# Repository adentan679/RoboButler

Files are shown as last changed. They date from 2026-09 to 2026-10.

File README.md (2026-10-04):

# RoboButler — Person-Following Rover with Gesture-Controlled Item Access

A robotics prototype developed for **UC San Diego ECE/MAE 148**, designed to follow an AprilTag target and provide access to stored items through a rotating compartment and motorized scissor lift.

**My role:** Hardware integration, Raspberry Pi–Arduino communication, motor control, power distribution, and debugging.

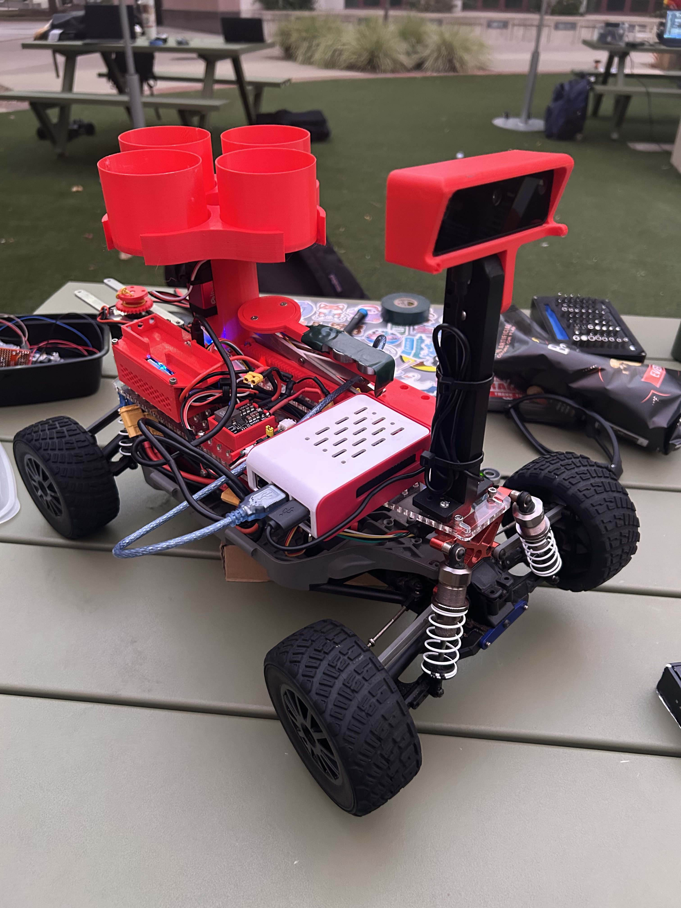
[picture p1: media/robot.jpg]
RoboButler assembled prototype


## Overview

Walking between classes across UCSD's large campus can be tiring, especially while carrying a heavy backpack. Our team explored a robot that could follow a student carrying an AprilTag and transport some of their belongings.

At the destination, hand gestures select a compartment position and extend a stepper-driven scissor lift to make items easier to reach. A fist commands the lift to retract. The intended lift travel was approximately a couple of feet; measured travel and payload capacity have not been established.

**Project status:** Navigation and gesture-controlled actuation were tested on hardware as course subsystems. This repository presents them as a **single coordinated application** with navigation-to-gesture handoff, actuator command tracking, camera ownership control, and return-to-navigation logic. The integrated software path has been validated with **62 automated tests** and a complete simulated operating sequence. The available project evidence does not establish an end-to-end physical test of this exact integrated build.

## Course Demonstrations

These videos document the two major hardware subsystems developed for the course. They demonstrate gesture-controlled actuation and AprilTag-based navigation work, rather than a complete end-to-end run of the current integrated application.

- [Hand Gesture Control Demonstration](https://youtu.be/hY5M1MJWAxY)
- [AprilTag Detection Demonstration](https://youtube.com/shorts/GXT1gASVuJs)

## My Contributions

My work focused on connecting and debugging the robot's electronics and actuators:

- Integrated Raspberry Pi-to-Arduino Mega USB serial communication for gesture-driven motor commands.
- Developed Arduino control for compartment servo positioning and stepper-driven lift extension and retraction.
- Wired and configured the DRV8825 stepper driver and investigated motor response and connection issues.
- Integrated power distribution for the vehicle electronics, servo, and stepper motor.
- Troubleshot wiring, serial communication, actuator operation, and driver overheating.
- Adjusted the driver's current-limit setting during hardware debugging.

One stepper driver overheated and was replaced. I recall reducing the replacement driver's reference voltage from approximately **1.0 V to 0.5 V** while troubleshooting heat. These are recalled Vref settings, not verified motor-current measurements; the current relationship depends on the actual driver module.

Navigation software and mechanical design were team efforts. The active repository combines the navigation, gesture, Arduino, and vehicle-control components under one supervisor while preserving the original course subsystem code in `archive/software/` for traceability.

## How the Integrated System Works

The Raspberry Pi runs a coordinator that manages navigation, camera ownership, gesture recognition, and Arduino commands. Because the navigation and gesture code use different DepthAI APIs, they run in **separate Python environments**, with only one vision process owning the OAK-D Lite at a time.

```mermaid
flowchart TD
    NAV["Navigate toward selected AprilTag"] --> STOP["Request vehicle stop"]
    STOP -->|"Operator confirms standstill"| GEST["Release navigation camera; start gesture mode"]
    GEST -->|"Selection gesture"| EXT["Rotate compartment and extend lift"]
    EXT -->|"Fist"| RET["Retract lift; remain parked"]
    RET -->|"Motion complete and operator confirms stow"| READY["Ready to resume"]
    READY -->|"Hold thumbs-up for two seconds"| SWITCH["Release gesture camera; restart navigation"]
    SWITCH --> NAV
```

The coordinator keeps the Arduino connection open across mode changes and requires a camera worker to release its resources and exit before starting the next worker. Gesture processing runs independently of the optional video preview.

**A completed movement command does not prove physical position.** Hardware mode still requires operator confirmation that the vehicle has stopped and that the lift is stowed. Thumbs-up replaces the typed resume command after stow confirmation. Navigation then requires a fresh observation of the selected tag; if the tag remains within the arrival threshold, the vehicle stays parked.

### Gesture Commands

| Gesture | Requested action |
|---|---|
| Point | Servo to 0°, then extend the lift |
| Peace | Servo to 90°, then extend the lift |
| Thumb, index, middle, and ring extended; pinky folded | Servo to 180°, then extend the lift |
| Open palm | Servo to 270°, then extend the lift |
| Fist | Retract the lift and remain parked |
| Upright thumbs-up held for two seconds | Resume navigation after confirmed stow |

These angles are inherited software settings. The physical servo's supported travel and pulse range still need verification. Additional compartment selections are blocked while the lift is extended or an actuator command is pending.

## Hardware and Software

| Area | Components and tools |
|---|---|
| Computing and vision | Raspberry Pi, OAK-D Lite, Arduino Mega |
| Vehicle control | RC chassis, VESC motor controller, drive motor, steering servo |
| Item access | Compartment servo, stepper motor, DRV8825 driver, scissor lift |
| Power | Approximately 15 V LiPo, anti-spark switch, actuator conversion to 5 V for the servo and 12 V for the motor supply |
| Navigation | AprilTag detection, RGB/depth processing, FastSAM, Pure Pursuit control |
| Gesture recognition | MediaPipe Hands, rule-based classification, gesture stability filtering |
| Integration | Python processes, USB serial, command acknowledgements, nonblocking Arduino firmware |

The navigation controller is named `mpc_controller.py`, but implements **Pure Pursuit steering and proportional command generation**, not optimization-based MPC. EKF code is present, but estimated velocity is overridden in the controller; this is not validated EKF-based speed feedback.

Hardware resources: [power distribution](hardware/schematics/power_distribution.png), [actuator wiring drawing](hardware/schematics/DRV8825_wiring_diagram.png), and [CAD files](hardware/cad/). The drawings document the project and require verification against the actual components before rebuilding. The CAD collection includes inherited chassis designs; a mount's presence does not establish that its corresponding sensor was used on RoboButler.

## Validation and Limitations

| Scope | Evidence and status |
|---|---|
| Course hardware work | Separate navigation and gesture/actuator subsystem testing |
| Integration software | Recorded run of **62 automated tests passing**, with no skips |
| Simulated sequence | Navigation → gesture mode → extension → retraction → confirmed stow → thumbs-up → navigation |
| End-to-end physical run of this exact integrated build | Not established by the available project evidence |

The automated checks exercise mode transitions, camera-process handoff, stale observations, serial failures, command acknowledgements, resume conditions, and firmware behavior with mocked hardware. The demo uses synthetic observations and simulated devices; it does not simulate vehicle dynamics, camera recognition accuracy, or lift mechanics. The firmware check compiles against host-side Arduino mocks, not the Mega toolchain.

Remaining work requires robot access: verify stopping and holding behavior, servo limits, stepper direction and travel, lift position sensing, payload capacity, Pi dependency compatibility, perception performance, and the complete operating sequence. Zero VESC duty may allow coasting and does not establish physical standstill.

See the [validation report](docs/validation.md), [recorded test output](docs/test-results.txt), and [demo output](docs/demo-output.txt).

## Try the Software Demo

From the repository root, using Python 3.10 or newer:

```bash
python run_robot.py --demo
```

No robot, camera, Arduino, DepthAI, or MediaPipe installation is needed for this demo. It should finish with:

```text
PASS: navigation -> gesture -> extend -> retract -> confirmed stow -> thumbs-up -> navigation
```

Run the automated checks with:

```bash
python -m unittest discover -s tests -v
```

Most checks use only Python's standard library. Three controller checks require NumPy, and the firmware check requires `g++`; those checks are skipped if their dependencies are unavailable. On Windows, use `py` if `python` is unavailable.

Hardware operation uses separate navigation and gesture environments and verified USB device identities. See the [integration guide](docs/integration-guide.md) for configuration, operator confirmations, and hardware prerequisites.

## Repository Guide

| Location | Contents |
|---|---|
| `run_robot.py` | Entry point for the demo and supervised hardware mode |
| `software/integration/` | Coordinator, process management, serial interfaces, and simulation |
| `software/navigation/` | Adapted team navigation code and FastSAM model |
| `software/gesture_control/` | Gesture classification and optional video preview |
| `software/arduino/` | Updated servo/stepper firmware for the integration protocol |
| `tests/` | Automated software tests and hardware mocks |
| `docs/` | Integration guide, serial protocol, validation, and source attribution |
| `hardware/` | Power and wiring drawings, CAD, and mounting designs |
| `media/` | Prototype photographs and assembly images |
| `archive/software/` | Original course subsystem code |

The original gesture application used Flask. The integrated application uses an optional read-only preview without Flask. Its Arduino firmware also uses an updated command protocol, so the archived sketch is not interchangeable with the integrated firmware.

## Team Project and Credits

Developed for **ECE/MAE 148 — Introduction to Autonomous Vehicles**, University of California, San Diego, Spring 2026.

This personal portfolio repository highlights my hardware integration, Arduino actuation, power distribution, and debugging contributions. Team-developed navigation software and mechanical designs are retained with attribution, and the active repository presents the project as one coordinated software system while preserving the original course snapshot for traceability.

- [Original team repository](https://github.com/UCSD-Silberman-Classes-and-Projects/spring-2026-final-project-team-17)
- [Source attribution and implementation notes](docs/sources.md)

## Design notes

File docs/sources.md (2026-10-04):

# Source attribution and implementation notes

Original team repository:
https://github.com/UCSD-Silberman-Classes-and-Projects/spring-2026-final-project-team-17/tree/5b2ddda989908b18566bfb2381e0f541582ae974

Navigation modules and FastSAM-s.pt originate in that revision's VisCarPath folder. Gesture landmark rules originate in hand_gesture/gesture_servo_stepper.py. Existing pin assignments, servo mapping and pulse-count settings originate in hand_gesture/project_servo_stepper.ino. Preserve the team's attribution and upstream dependency/model licenses if redistributing this project; this package does not assert a new license over those materials.

Current repository integration layer: supervisor, worker protocol/lifecycle, persistent serial adapters, default simulator, tests and protocol firmware. Adapted for the unified application: camera-only navigation mode, freshness checks, near-endpoint following, FastSAM thread shutdown/failure propagation and VESC stop/port behavior. The original FastSAM weights are copied unchanged; no model inference/training was performed here.

Official API references consulted:

- Luxonis DepthAI v2/v3 migration: https://docs.luxonis.com/software-v3/depthai/tutorials/v2-vs-v3
- Luxonis v3 camera context and output queues: https://docs.luxonis.com/software-v3/depthai/examples/camera/camera_output
- Luxonis host-synchronized monotonic timestamps: https://docs.luxonis.com/software-v3/depthai/depthai-components/device

Hardware mode targets the Raspberry Pi's Linux host. getTimestamp() is the DepthAI host-synchronized monotonic time; getTimestampDevice() is not used for supervisor message age. Pi-side camera/API and installed-wheel compatibility still require validation on that platform.

Gesture-resume update: added a scale-relative upright-thumb rule, timed hold with stow/motion gates, and simulated coverage. The existing selection rules and integrated Arduino firmware are retained.

The active `software/` tree is the current unified implementation. `archive/software/` preserves the original course subsystem snapshot so the source lineage and later coordination changes remain traceable.

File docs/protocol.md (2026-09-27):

# Host/Arduino protocol and ownership

The supervisor owns the Arduino port throughout both modes. Camera workers never write USB serial. The VESC has its own sole writer thread; no other process should run a standalone VESC program concurrently.

Arduino baud: 9600. Lines are ASCII and newline-terminated. Firmware input is bounded to 63 characters. Motion uses a nonblocking loop so PING and STOP can be handled during movement.

| Host message | Arduino response / behavior |
|---|---|
| `HELLO` | `READY ROBOBUTLER1`; establishes heartbeat link |
| `PING` | `PONG`; host sends every 0.5 s |
| `1 STOW` | `ACK 1`, `DONE 1 STOWED`; operator confirmation, no motor movement |
| `2 Command_1` | `ACK 2`; rotate then extend; `DONE 2 EXTENDED` after pulse generation |
| `3 RETURN` | `ACK 3`; retract; `DONE 3 RETRACTED_UNVERIFIED` |
| `STOP` | Stop step pulses, invalidate position; `FAULT STOPPED` |

Use increasing positive command IDs; do not reuse or blindly retry a motion after losing its reply. There is only one pending command. STOW is permitted at boot/unknown or after retraction, not while extended or moving. A selection requires STOWED. RETURN requires EXTENDED. ACK means accepted, DONE means software action finished. Neither message is a position measurement.

Firmware emits `BOOT ROBOBUTLER1` at startup. Receiving BOOT after the host handshake faults the session and invalidates position. Lack of host heartbeat for over two seconds also stops firmware motion and invalidates position. The firmware has no home sensor; automatic position recovery is intentionally absent.

Camera workers send JSON lines with an integer session token and event type. Observation messages include a strictly increasing frame sequence and a host monotonic capture timestamp. Old sessions and repeated frames cannot authorize a new action. READY confirms worker initialization; RELEASED is emitted only after camera cleanup. The parent also requires successful process exit before starting the next owner. Release failure/timeout never permits concurrent camera startup.

The same coordinator consumes simulated and real worker messages. Tests use synthetic detections to validate coordination, not to estimate real-world computer-vision accuracy.

Resume uses a `THUMBS_UP` vision label held for two seconds on fresh frames after acknowledged physical stow. It is handled entirely by the coordinator and is never sent to the Arduino. The terminal `resume` action has been removed. Retraction completion alone still cannot authorize resumption.

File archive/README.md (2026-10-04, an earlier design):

# Original Course Code

This folder preserves the original RoboButler navigation and gesture-controlled actuation code from UC San Diego ECE/MAE 148.

The active implementation lives in the repository root and [`software/`](../software/). It combines navigation, gesture recognition, Arduino actuation, camera handoff, safety interlocks, and return-to-navigation behavior under one supervisor.

This archive is retained only for source traceability and comparison with the active integrated implementation. See the [main README](../README.md) for the current project architecture and validation status.

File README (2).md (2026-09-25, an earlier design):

# Robobutler — Person-Following Rover with Gesture-Controlled Item Access

A robotics prototype developed for **UC San Diego ECE/MAE 148** that combines AprilTag-based navigation with a rotating storage compartment and a motorized scissor lift.

**My role:** Hardware integration, Arduino motor control, power distribution, and system debugging.

<!-- Add a clear photo of the assembled robot here:
![Robobutler assembled prototype](media/robobutler.jpg)
-->

## Overview

Walking between classes across UCSD's large campus can be tiring, especially while carrying a heavy backpack. Our team wanted to explore a robot that could follow a student and carry some of their belongings.

Robobutler uses an **AprilTag as the visual target** for following a person. To make stored items easier to reach, the design combines a **servo-driven rotating compartment** with a **stepper-driven scissor lift**. Hand gestures select a compartment position and command the lift to extend or return. The intended lift travel was approximately a couple of feet, bringing items closer to the user's reach.

The project consists of two subsystems: autonomous navigation and gesture-controlled actuation. **These subsystems were tested separately; automatic transition from navigation to gesture control remains future work.** The prototype explores the campus carrying concept; backpack payload capacity and full campus operation have not been established in the project documentation.

## My Contributions

My work focused on connecting the robot's electronics, power system, and actuators:

- Integrated Raspberry Pi-to-Arduino Mega USB serial communication to translate gesture commands into motor actions.
- Developed Arduino control for servo positioning and stepper-driven extension and retraction of the mechanism.
- Wired and configured the DRV8825 stepper driver, including STEP/DIR control and motor connections.
- Designed and tested power distribution for the motors and control electronics.
- Tuned the stepper driver's current limit and investigated overheating and unreliable motor operation.
- Tested and debugged wiring, serial communication, and actuator response during subsystem integration.

The navigation software and mechanical design were team efforts. This repository highlights my hardware and actuation contributions while documenting the broader project.

## Intended Operation

1. The user carries an AprilTag that serves as the robot's tracking target.
2. The rover navigates toward the tag while carrying items.
3. After the rover stops near the user, a hand gesture selects a storage position.
4. The servo rotates the compartment, and the stepper motor extends the scissor lift to present the items.
5. A fist gesture commands the lift to return.

This sequence describes the intended integrated experience. Navigation and gesture actuation currently run as separate subsystems.

## System Architecture

### Autonomous Navigation

The OAK-D Lite supplies RGB and depth data for AprilTag detection and ground/obstacle perception. The navigation code includes FastSAM segmentation, EKF state estimation, path planning, and a Pure Pursuit-based controller that sends throttle and steering commands through the VESC.

Although the controller source is named `mpc_controller.py`, the included implementation uses a geometric Pure Pursuit approach rather than an optimization-based MPC controller. EKF code is present, but the current controller does not use its estimated velocity for speed feedback.

### Gesture-Controlled Actuation

The Raspberry Pi processes OAK-D Lite images with MediaPipe Hands and sends text commands to the Arduino Mega over USB serial. The Arduino positions the compartment servo and sends STEP/DIR signals to the DRV8825 to move the scissor lift.

The firmware supports four configured compartment positions. Once the lift is extended, additional position-selection commands are ignored until a return command retracts it. A Flask video stream displays gesture recognition results for testing.

<!-- Add a signal-flow diagram here:
![System signal flow](media/system_architecture.png)
-->

## Hardware and Software

| Area | Components and tools |
|---|---|
| Computing and vision | Raspberry Pi, OAK-D Lite, Arduino Mega |
| Vehicle control | RC car chassis, VESC motor controller, drive motor, steering servo |
| Item access | Compartment servo, stepper motor, DRV8825 driver, scissor-lift mechanism |
| Power | LiPo battery, DC-DC converters / UBEC, motor and logic power wiring |
| Software | Python, Arduino C/C++, DepthAI, OpenCV, MediaPipe, PySerial, Flask |
| Navigation | AprilTag detection, NumPy/SciPy, FastSAM, Pure Pursuit control |

## Results and Limitations

The team repository documents separate testing of the navigation and gesture-control subsystems, including camera processing, VESC command output, Raspberry Pi-to-Arduino communication, and servo/stepper operation.

Remaining work includes:

- Integrating the automatic transition from navigation to gesture mode.
- Coordinating access to the shared OAK-D Lite camera.
- Improving navigation tuning and testing repeatability.
- Measuring lift travel, payload capacity, and reliability under load.
- Validating the complete carrying-and-item-access sequence.

The existing navigation code uses **DepthAI 2.x**, while the documented gesture setup uses **DepthAI 3.6.1**. These versions require separate software environments unless the code is updated.

## Repository Guide

The portfolio repository is organized around the following areas:

| Folder | Contents |
|---|---|
| `software/gesture_control/` | Raspberry Pi gesture recognition and serial communication |
| `software/arduino/` | Servo and stepper control firmware |
| `software/navigation/` | Team navigation code and setup notes |
| `hardware/` | Wiring diagrams, power distribution, component details, and selected CAD files |
| `docs/` | Testing results and debugging notes |
| `media/` | Prototype photos, diagrams, and demonstration images |

<!-- Populate these folders before publishing this guide. -->

## Demonstrations

<!-- Add real media before publishing:
- A short video showing compartment rotation, lift extension, and retraction.
- A separate AprilTag navigation video, labeled as a subsystem demonstration.
- Photos of the mechanism in its lowered and raised positions.
Use a video-hosting link for full videos rather than committing large video files.
-->

Demonstration media will document navigation and gesture-controlled actuation separately.

## Team Project and Credits

Developed for **ECE/MAE 148 — Introduction to Autonomous Vehicles**, University of California, San Diego, Spring 2026.

This is a personal portfolio version of a team project. My contributions focus on hardware integration, power distribution, Arduino actuation, and debugging. Team-developed navigation software and mechanical designs are included with attribution.

[Original team repository](https://github.com/UCSD-Silberman-Classes-and-Projects/spring-2026-final-project-team-17)

<!-- Add teammates' names and specific design/code credits when copying their work. -->

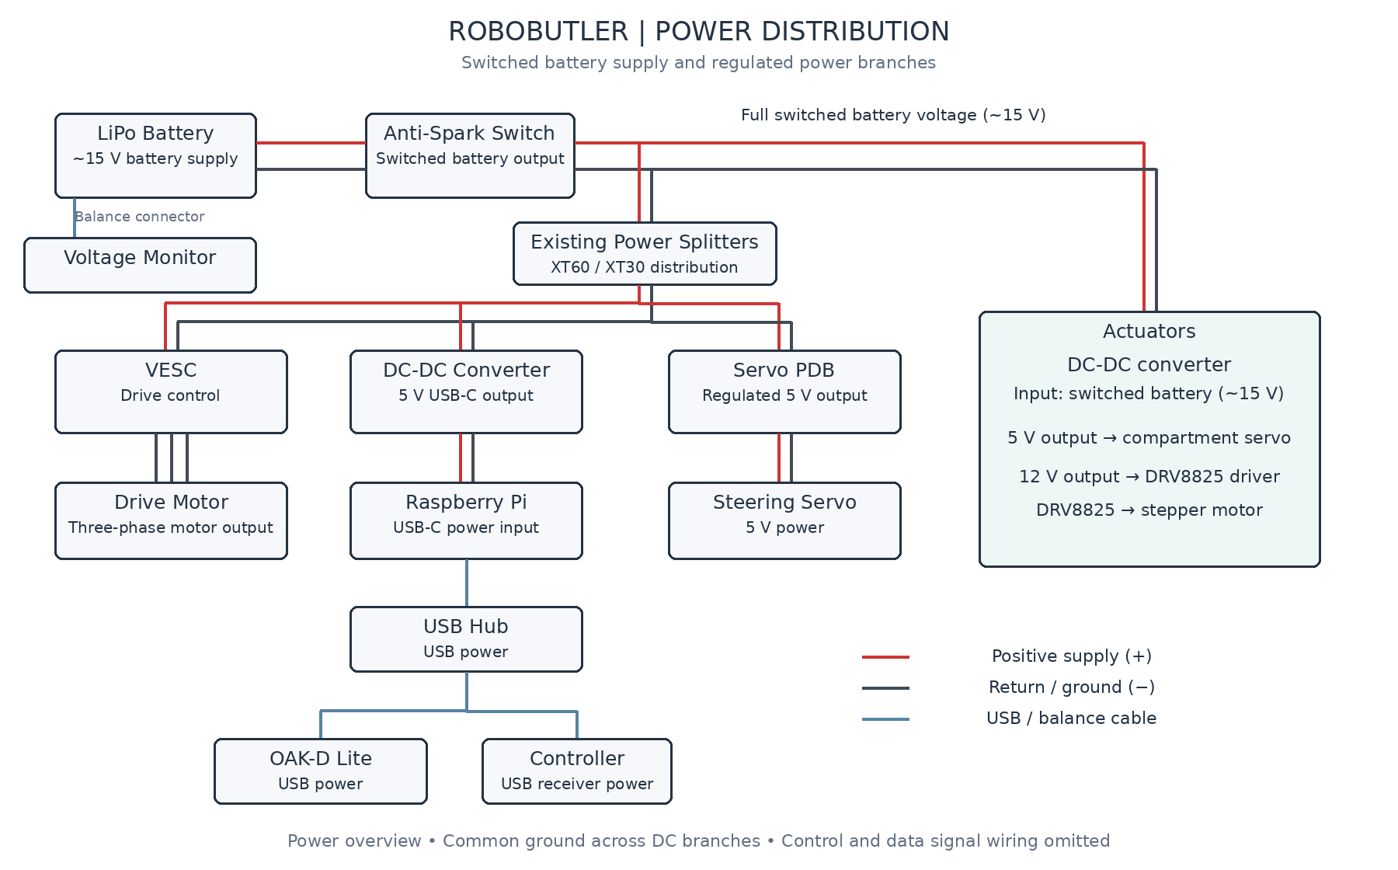
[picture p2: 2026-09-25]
hardware/schematics/power_distribution.png

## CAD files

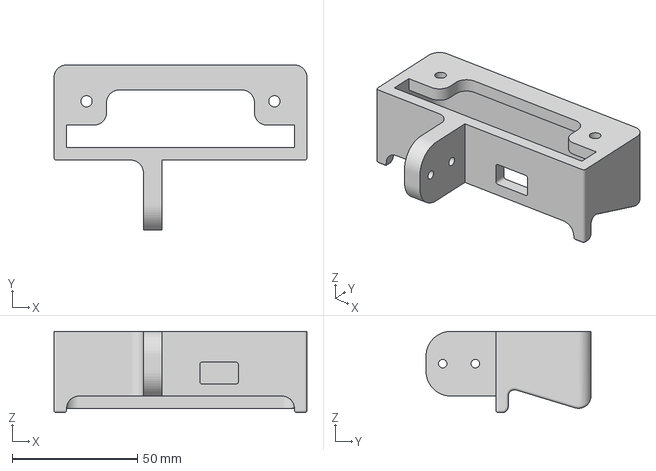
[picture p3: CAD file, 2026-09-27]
hardware/cad/MAE 148 T17 Visor Camera Mount.3mf
101.0 x 65.9 x 32.5 mm

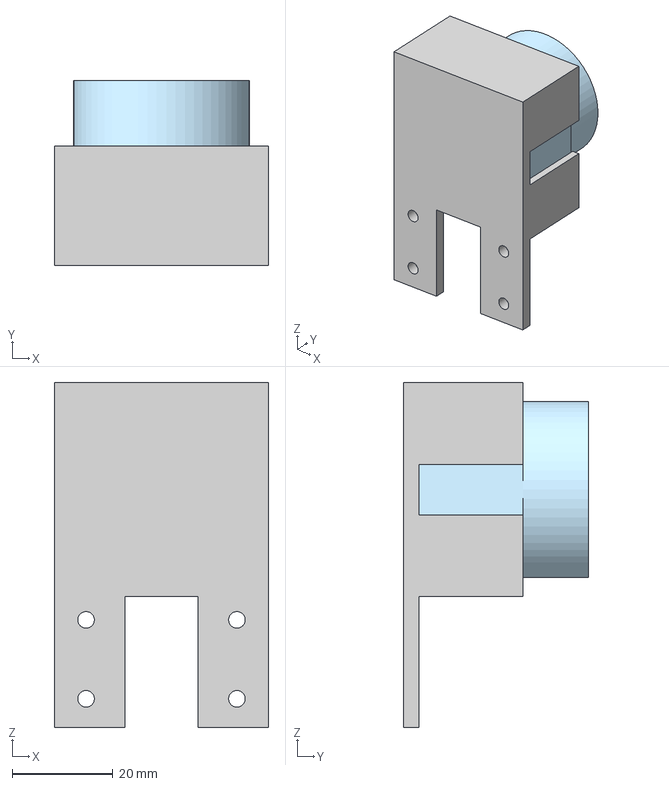
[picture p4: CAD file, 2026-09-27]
hardware/cad/MAE 148 T17 Lidar Mount.3mf
42.6 x 36.7 x 68.6 mm
LIDAR
LIDAR mount

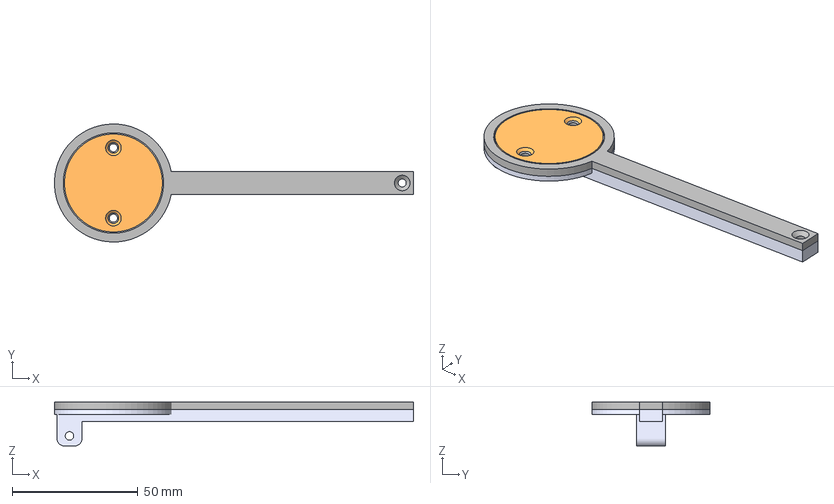
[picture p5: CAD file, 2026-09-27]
hardware/cad/MAE 148 T17 Top Linkage.3mf
143.0 x 47.0 x 17.5 mm
Linkage Cap
Linkage Bottom
Linkage Top

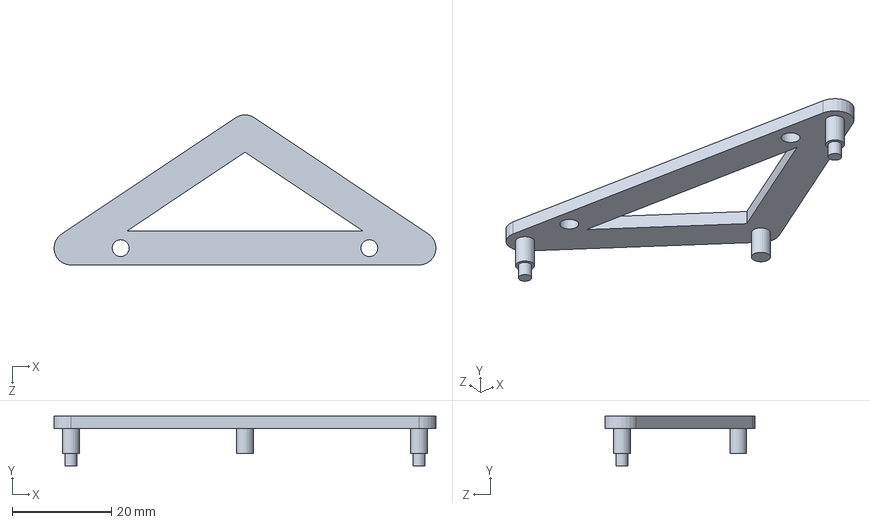
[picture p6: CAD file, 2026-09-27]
hardware/cad/RaspPI Holder.SLDPRT
76.8 x 10.0 x 30.2 mm

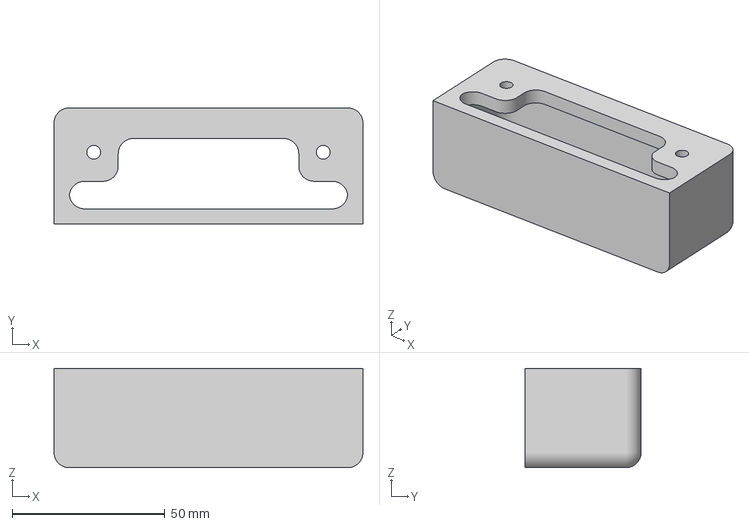
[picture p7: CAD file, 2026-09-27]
hardware/cad/MAE 148 T17 Basic Camera Mount.3mf
101.0 x 38.0 x 32.5 mm

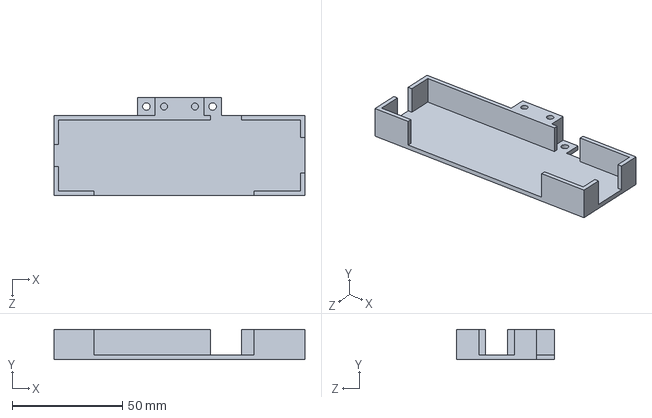
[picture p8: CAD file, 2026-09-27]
hardware/cad/MAE148 USBPortHolder.SLDPRT
113.7 x 13.6 x 44.2 mm

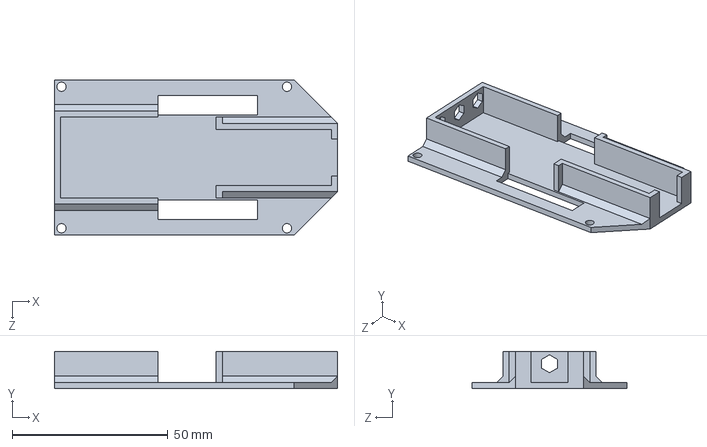
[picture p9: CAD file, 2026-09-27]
hardware/cad/MAE148 FSESC6.6 Mount COVER.SLDPRT
91.0 x 12.0 x 50.0 mm

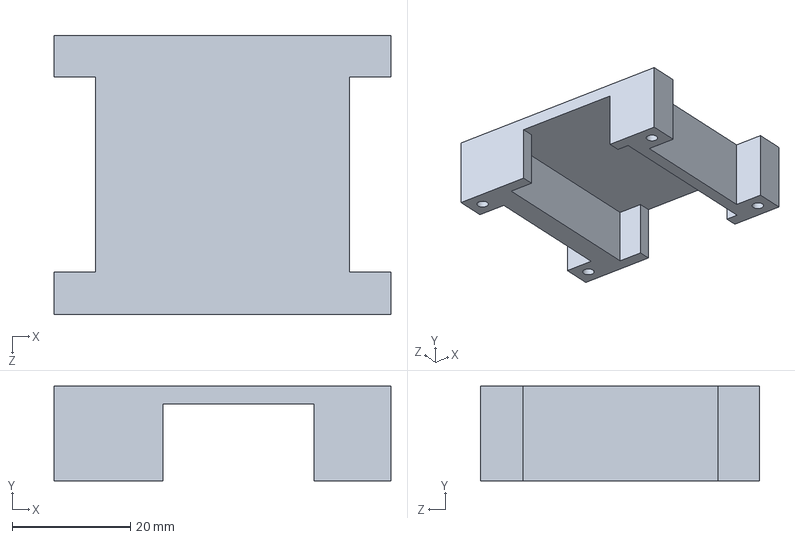
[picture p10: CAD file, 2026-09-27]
hardware/cad/MAE148 CircuitBoardHolder.SLDPRT
57.0 x 16.0 x 47.2 mm

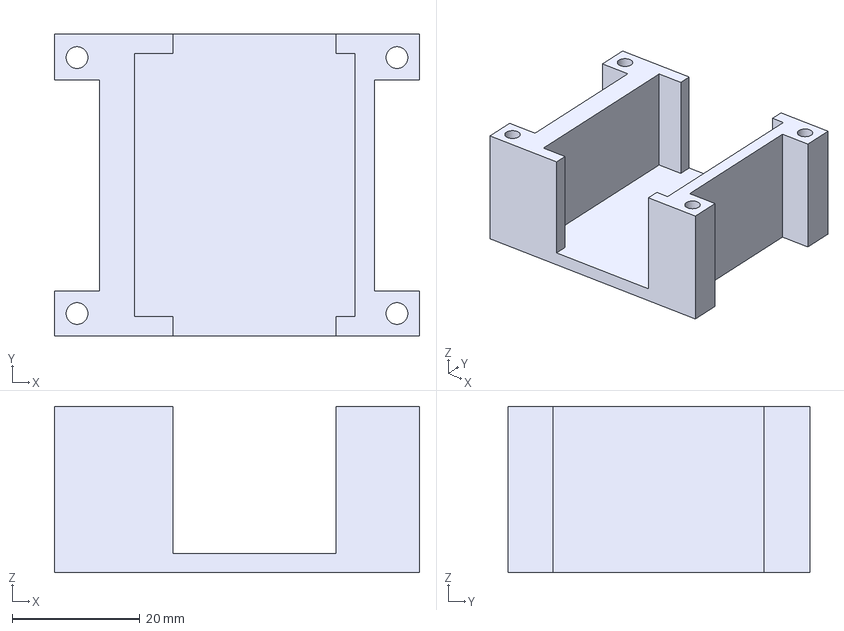
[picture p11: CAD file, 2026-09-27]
hardware/cad/MAE 148 T17 CircuitBoardHolder.3mf
57.0 x 47.2 x 26.0 mm

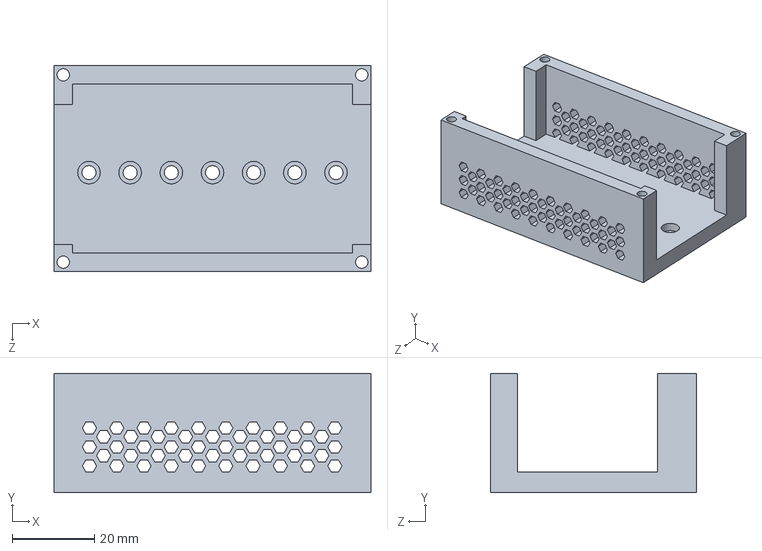
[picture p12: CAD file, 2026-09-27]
hardware/cad/MAE148 FSESC6.6 Mount V3.SLDPRT
77.0 x 29.0 x 50.0 mm

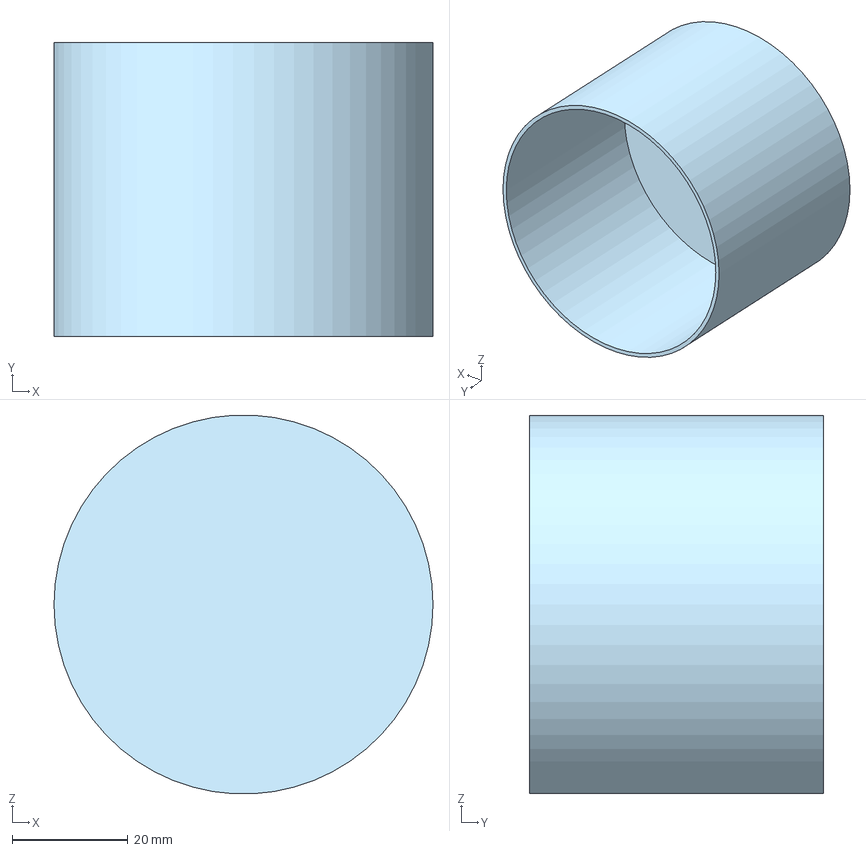
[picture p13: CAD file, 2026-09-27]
hardware/cad/MAE 148 T17 Magnetic Cup.3mf
65.5 x 50.8 x 65.4 mm

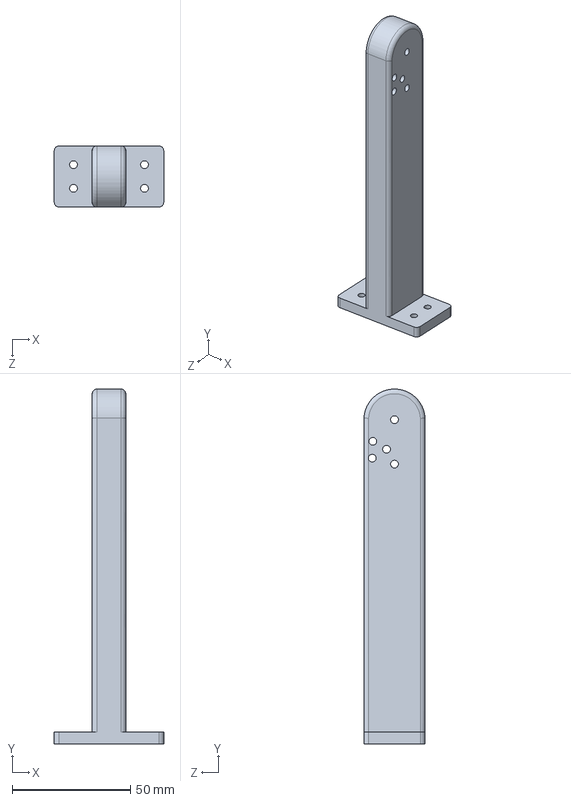
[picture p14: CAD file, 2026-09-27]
hardware/cad/MAE 148 T-7 Camera Stand v3.SLDPRT
46.3 x 150.0 x 25.9 mm

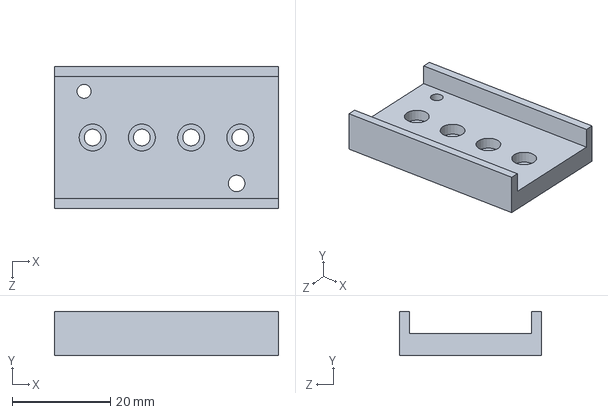
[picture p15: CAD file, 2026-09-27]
hardware/cad/MAE148 ServoPDBHolder.SLDPRT
45.5 x 9.00 x 28.8 mm

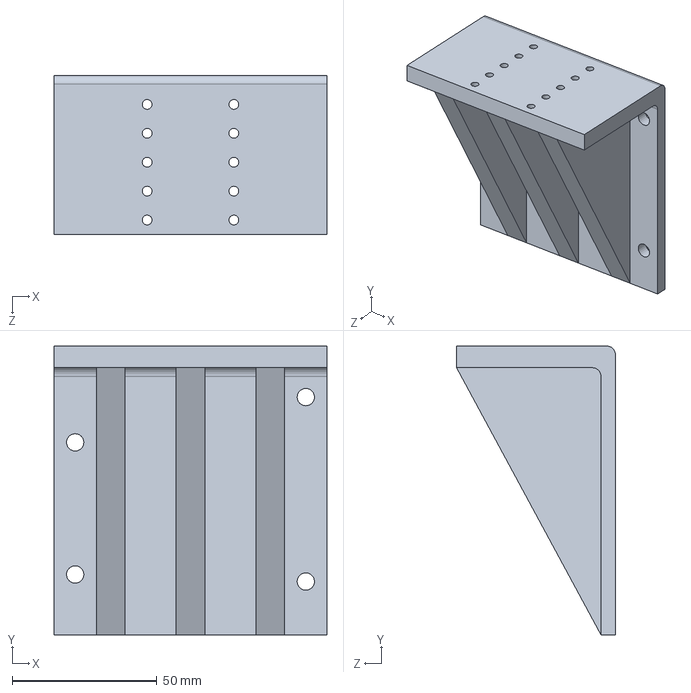
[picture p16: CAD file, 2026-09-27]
hardware/cad/MAE148 FSESC6.6 Mount V!.SLDPRT
94.4 x 100.0 x 55.0 mm

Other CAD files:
hardware/cad/Camera Assembly.SLDASM
hardware/cad/MAE 148 T-7 Visor Mount v2.sldprt
hardware/cad/MAE148 AntennaCover.SLDPRT
hardware/cad/MAE148 CameraStand CHWEN.SLDPRT
hardware/cad/MAE148 BasePlate.SLDPRT
hardware/cad/MAE148 CameraArm CHWEN.SLDPRT
hardware/cad/MAE148 DCConverterHolder.SLDPRT
hardware/cad/MAE148 FSESC6.6 Mount V2.SLDPRT
hardware/cad/MAE148 GPSHolder.SLDPRT
hardware/cad/MAE148 PowerSwitchHolder.SLDPRT
hardware/cad/MAE148 USBPortHolderCOVER.SLDPRT

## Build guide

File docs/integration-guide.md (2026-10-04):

# RoboButler: integrated navigation and gesture control

**Start with the simulator. No robot, camera, Arduino, DepthAI, or MediaPipe installation is needed for the demo.** The repository root and `software/` contain the active unified implementation, including navigation, gesture recognition, actuator control, device ownership, and system-level coordination. The original course subsystem snapshot is preserved in `archive/software/` for traceability. The integrated software path is validated by the automated suite; the available project evidence supports hardware testing of the subsystems rather than an end-to-end physical validation of this exact build.

The integrated application requires the `ROBOBUTLER1` Arduino firmware in `software/arduino/project_servo_stepper/`. The archived course sketch uses a different protocol and is not compatible with this application. Thumbs-up return is handled by the Python coordinator; it does not send an Arduino resume command.

## Run on your computer

Clone or download this repository, then open a terminal in the repository root—the folder containing `run_robot.py`—and run:

```bash
python run_robot.py --demo
```

On Windows, if `python` is unavailable but the Python launcher is installed:

```powershell
py run_robot.py --demo
```

Python 3.10+ is recommended. The demo uses only the Python standard library. It starts real child processes with synthetic camera observations, simulates Arduino replies, and exercises the same coordinator and serial-response parser used in hardware mode. It should finish in a few seconds with:

```text
PASS: navigation -> gesture -> extend -> retract -> confirmed stow -> thumbs-up -> navigation
```

It then shuts down and releases its simulated camera. A loopback socket on port 47831 represents exclusive camera ownership; no external network connection is made. Run one demo/test suite at a time. If that port is already in use, close the other demo or choose `simulation_camera_port` in your config.

Run the tests:

```bash
python -m unittest discover -s tests -v
```

Most tests need only Python. Three actual path-controller tests require NumPy. The optional native Arduino test requires `g++`; those tests are reported as skipped when their dependencies are unavailable. To include the controller checks, install NumPy in a test environment. The recorded validation run passed all 62 tests without skips. See the [validation report](validation.md) and [test output](test-results.txt).

## What is integrated

- A single coordinator controls navigation, stopping, camera release, gesture mode, actuator motion and return to navigation.

- Navigation and gesture camera workers use separate interpreters, retaining DepthAI v2 and v3 respectively.

- One parent-owned VESC writer accepts expiring drive commands. It continues sending zero duty during gesture mode, worker startup and handoff.

- One Arduino USB connection stays open for the entire session. Switching camera workers does not reopen/reset the Arduino.

- Navigation must release its camera **and exit successfully** before the gesture worker is launched; the same rule applies in the other direction.

- Gesture inference runs continuously on fresh frames, whether or not anyone opens the optional preview.

- Five fresh observations stabilize a gesture. Holding a gesture fires it once; changing to another stable gesture permits a new command. Three neutral frames rearm the same gesture.

- Command IDs and ACK/DONE replies associate each movement with its completion. The coordinator accepts only one actuator command at a time.

- The near-target controller now uses a valid closer endpoint instead of rejecting all waypoints within 1.2 m.

- Arrival is latched by the coordinator. Tag movement does not automatically restart the vehicle while serving the user.

## Mode sequence and return behavior

```mermaid
flowchart TD
    A["Navigation: selected tag"] -->|"Arrival confirmed across fresh frames"| B["Stop requested"]
    B -->|"Operator confirms stopped"| C["Release navigation camera and await exit"]
    C --> D["Gesture mode"]
    D -->|"Selection gesture"| E["Rotate and extend"]
    E -->|"Fist"| F["Retract; await completion"]
    F -->|"Confirm stowed, then hold thumbs-up"| G["Release gesture camera and await exit"]
    G --> A
```

The full supervisor also includes BOOT, worker-startup, FAULT and SHUTDOWN states. See `software/integration/core.py`.

**Fist retracts and leaves the vehicle parked.** It never directly resumes driving. Resume requires completed motion, a physical stow confirmation and an upright thumbs-up held for two seconds. The typed `resume` command is no longer accepted. On re-entering navigation, the robot needs a fresh observation of the same selected tag. If the tag is still inside the arrival threshold, it stays parked.

Because the reviewed robot has no established physical standstill or lift-home feedback, this implementation uses local operator confirmations in hardware mode. The simulator supplies those observations automatically as test inputs. A firmware DONE message never becomes proof of physical retraction. Automatic unattended transitions would require verified sensing and stop/hold behavior, not just changing a software flag.

## Included files

| Location | Purpose |
|---|---|
| `run_robot.py` | Single entry point for demo and supervised hardware operation |
| `config.example.json` | Mode thresholds, deadlines, device paths, interpreter paths |
| `software/integration/core.py` | Shared mode logic and interlocks |
| `software/integration/processes.py` | Starts/stops vision workers and validates their messages |
| `software/integration/vision_worker.py` | Production navigation and gesture camera loops |
| `software/integration/hardware.py` | Persistent Arduino protocol and VESC command-expiry thread |
| `software/integration/simulation.py`, `sim_worker.py` | Fake devices and synthetic camera subprocesses |
| `software/navigation/` | Adapted team navigation code and original FastSAM weights |
| `software/gesture_control/` | Landmark classifier, optional read-only preview, dependencies |
| `software/arduino/project_servo_stepper/` | New nonblocking firmware with the integration protocol |
| `tests/` | Coordinator, serial, subprocess, controller, vision-worker and firmware checks |
| `docs/` | Validation results, protocol, limitations and source attribution |

## Gesture mapping

| Gesture | Command | Requested action |
|---|---|---|
| Point | `Command_1` | Servo 0°, then extend |
| Peace | `Command_2` | Servo 90°, then extend |
| Thumb + index + middle + ring, pinky folded | `Command_3` | Servo 180°, then extend |
| Open palm | `Command_4` | Servo 270°, then extend |
| Fist | `RETURN` | Retract; remain parked |
| Upright thumbs-up, four fingers folded | Supervisor only | Hold for two seconds after confirmed stow to return to navigation |

The original FOUR-finger condition was mislabeled THREE. The integrated classifier calls it `FOUR`; the physical rule and command mapping are otherwise retained. The rule-based classifier remains orientation-sensitive and has not been visually revalidated here. Keep the thumb pointing upward in the camera image with the other four fingers folded. A missing hand, another gesture, or a gap over 0.3 seconds between fresh detections restarts the resume hold. The hold starts only after stow acknowledgement and no pending actuator command. Its duration and maximum capture gap are configurable as `resume_hold_seconds` and `resume_max_gap_seconds`.

## Hardware setup

You do not need these steps to run the demo.

1. Retain a backup of the team firmware. The integrated host requires the `ROBOBUTLER1` firmware in this repository; the old sketch's free-text replies are incompatible. Open `software/arduino/project_servo_stepper/project_servo_stepper.ino` in Arduino IDE, select Arduino Mega and compile/upload during a supervised bench session. The host-side test is not an AVR-board compilation.

2. Verify the actual servo permits the existing 500–2500 µs / 270° mapping. Verify DRV8825 wiring, current setting, direction, microstepping and travel. The existing 300 pulses per movement and 1000 µs half-period are retained as configuration, not measured revolutions or safe lift limits. Pins remain servo D5, DIR D2, STEP D3, baud 9600; enable D8 remains unused.

3. Create/reuse separate Pi environments. Install `requirements.txt` in the supervisor environment, `software/navigation/requirements.txt` in the navigation environment and `software/gesture_control/requirements.txt` in the gesture environment. Do not merge the DepthAI v2/v3 dependencies into one environment. Pi wheel availability and full dependency resolution were not tested here.

4. Copy `config.example.json` to `config.local.json`. Set both absolute Python interpreter paths and physically verified, distinct `/dev/serial/by-id/` device paths. No numbered-port fallback exists. The software cannot independently authenticate the VESC from the path name.

5. Set the selected AprilTag ID and measured black-square tag size. `0.15 m` and arrival distance `0.5 m` are inherited starting values, not calibration results. Arrival is camera-to-tag range, not bumper clearance. Establish actual stopping/holding behavior and the VESC's own loss-of-command timeout. Zero duty can coast and does not guarantee a stationary vehicle.

6. Only after reviewing those hardware settings, set `hardware_reviewed` to `true` and run:

```bash
python run_robot.py --hardware --config config.local.json
```

The original team model file is included at `software/navigation/FastSAM-s.pt`. Paths in config for model weights are relative to the repository root; interpreter paths must be absolute.

The terminal commands are:

| Command | Meaning |
|---|---|
| `stowed` | Confirm you physically checked that the lift is retracted and the compartment is safe for vehicle movement; records the state through the Arduino protocol |
| `start` | Begin navigation after startup stow acknowledgement |
| `stopped` | At STOPPING, confirm the vehicle is physically stopped and held stationary; allows handoff to gestures |
| `status` | Show mode, lift state and pending command |
| `quit` | Request shutdown |

At startup: `stowed`, wait for `ACTUATOR STOWED`, then `start`. At arrival: verify standstill, then `stopped`. After using gestures and retracting: verify stow, issue `stowed`, wait for acknowledgement, then hold an upright thumbs-up for two seconds. You no longer type `resume`.

Optional preview: set `preview_port` to `5000` and visit `http://127.0.0.1:5000` on the Pi. For viewing from a laptop use an SSH port forward, e.g. `ssh -L 5000:127.0.0.1:5000 pi@YOUR_PI`, then open the laptop's `http://127.0.0.1:5000`. The preview is read-only, only available during gesture mode, and can be left disabled.

## Failure behavior and limits

- Target loss or obstruction withdraws the driving command. A different tag cannot take over.

- Stale frames, startup/release timeouts, worker crashes, serial errors, missing movement completion and Arduino reset latch FAULT. There is no automatic reconnect-and-drive path.

- A VESC writer thread expires drive permission even if the supervisor stops refreshing it. Pi/process failure still requires a controller-side timeout; the software thread is not a hardware emergency stop.

- On fault/shutdown, the host requests zero drive and sends Arduino STOP. Firmware stops generating step pulses, invalidates position and holds existing outputs. It does not automatically retract, detach the servo or disable stepper holding torque.

- Recovery requires resolving the failure and restarting, with physical state verification. Reopening USB may reset the Mega. The new sketch makes no servo move at boot, but electrical/mechanical reset behavior still needs testing.

- Existing perception and path-planning algorithms are retained. FastSAM, AprilTag accuracy, obstacle masking, camera calibration, speed, slopes, payload and physical stops have not been validated by these tests. The controller still overrides EKF velocity with zero, and the bridge retains its 0.07 fixed positive-duty mapping. This is not validated closed-loop speed control.

- Freshness thresholds can cause faults on an overloaded Pi. Measure processing latency before tuning them; increasing a timeout also increases the maximum age of a drive request.

The active repository is the unified RoboButler implementation. The original course subsystem snapshot remains in `archive/software/`, while the current supervisor connects navigation, gesture recognition, Arduino actuation, and return-to-navigation behavior into one software flow. The integrated sequence is validated in software; end-to-end physical verification of this exact build is not documented in the available project evidence. See the [project overview](../README.md) and [original course code](../archive/software/).

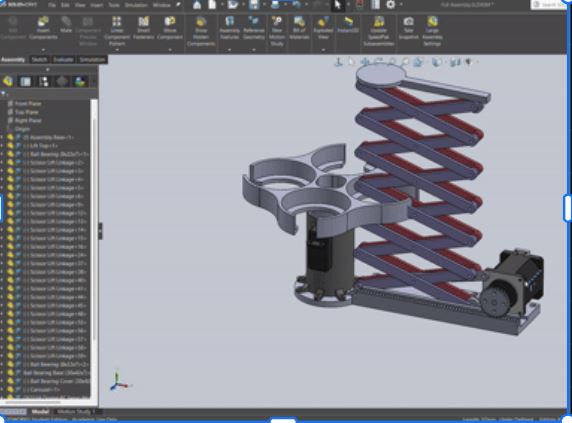
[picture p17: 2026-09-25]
media/full_assembly_sldwrks.JPG

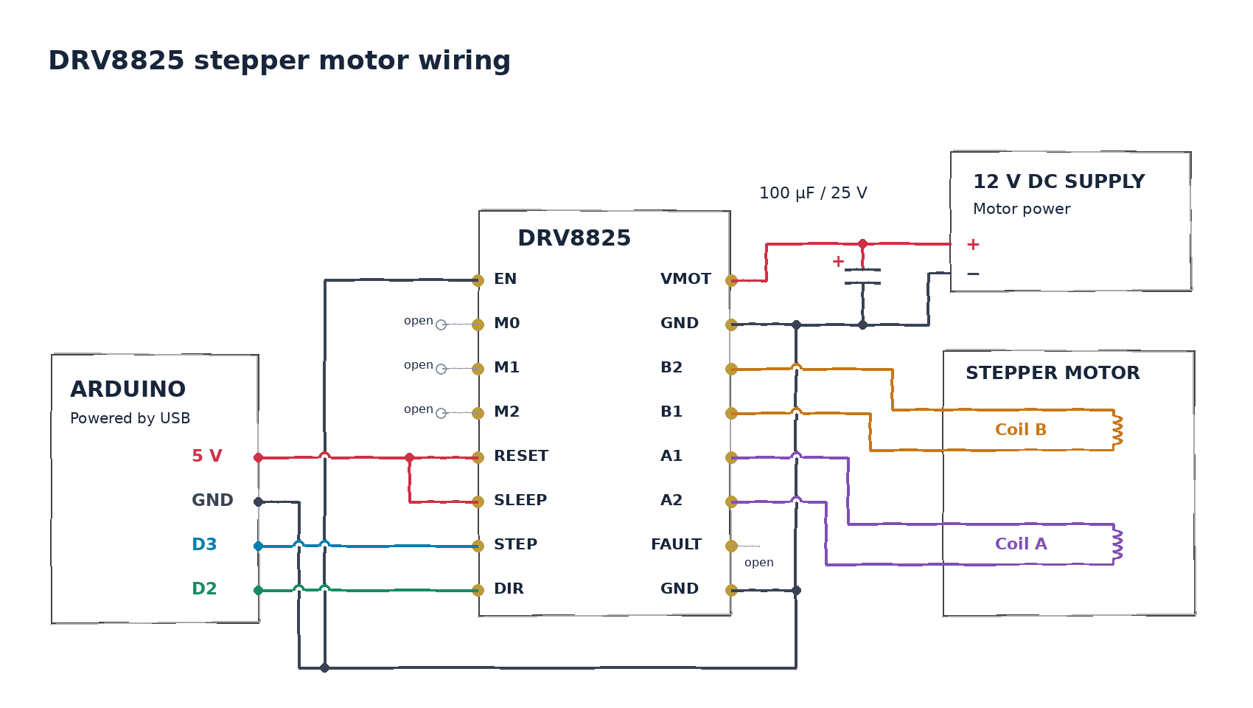
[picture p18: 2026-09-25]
hardware/schematics/DRV8825_wiring_diagram.png

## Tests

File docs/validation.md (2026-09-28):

# Validation report

**Result: 62 automated tests passed, zero failures, zero skips.** The default subprocess demo also completed successfully in a separate run. All Python files passed syntax compilation. Full captured outputs are in `test-results.txt` and `demo-output.txt`.

Validation environment: Linux x86_64, Python 3.12.14, NumPy 2.3.5, g++ 13.3.0. These are test-environment versions, not a claim that the Pi vision environments were installed or tested. The gesture requirements preserve the team's documented versions, including NumPy 1.26.4.

| Test group | Tests | What was exercised |
|---|---:|---|
| Coordinator and gesture filter | 24 | Full round trip; explicit stopped/stowed gates; fresh target on resume; both release and process exit; target loss; obstacles; wrong tag; stale/duplicate frames; old sessions; busy actuator; all gesture commands; held gestures; missing/wrong completions; Arduino reset; worker crash; invalid commands; shutdown |
| Serial/drive/process adapters | 8 | Partial serial lines, legacy firmware rejection, serial disconnection, port identity constraints, independent drive expiry, drive write failure, real child-process handoff and released camera ownership |
| Actual path controller | 3 | Positive command for valid near endpoints at 1.0/0.6 m; empty/behind path stop; obstacle stop |
| VESC bridge | 9 | Immediate zero-duty packet, negative input behavior, missing port, numbered-port rejection, connection/write failures, cleanup, short writes, nonfinite commands |
| Production vision-worker loops with mock APIs | 3 | Fresh frames once each without browser clients, close/release lifecycle, navigation camera-only mode, camera error cleanup |
| Actual Arduino sketch under native mocks | 1 | Host compilation with warnings treated as errors; handshake; no boot servo movement; servo selection; 300 pulses each way; unverified retraction state; STOP; busy/duplicate-ID rejection; heartbeat timeout; bounded serial input |
| Actual FastSAM thread lifecycle methods with model stub | 1 | Thread shutdown and inference-failure propagation |
| Thumbs-up resume and classifier | 13 | Two-second hold; interruptions and capture gaps; busy/extended/unverified stow rejection; duplicate and pre-confirmation frames; drive fault; typed-resume rejection; synthetic landmark mapping and hold configuration |
| **Total** | **62** | **All passed** |

The process demo uses the actual ProcessWorkers launcher and production coordinator/Arduino parser. Synthetic camera workers run as separate OS processes. A loopback socket represents exclusive OAK-D ownership: a second concurrent owner cannot bind it, and the OS releases ownership even if a simulated process dies. The demo returns to navigation and obtains a fresh nonzero drive request only after its simulated stow confirmation and a two-second thumbs-up. There is no typed-resume call in the demo. Its VESC and Arduino transport are fake.

During validation, a file-based simulated camera marker was found capable of persisting after a prior interrupted run. It was replaced with OS-owned socket lifetime. A subsequent complete test run and separate demo run passed. Production camera ownership is still managed by worker cleanup plus confirmed process exit, not by this simulation socket.

## What the passing tests establish

The exercised mode sequence, command interlocks, serial protocol handling, worker lifecycle and failure responses behave as specified for the tested inputs. Tests execute production coordinator/adapter code. The firmware test includes the actual `.ino`, not a rewrite of its motion logic.

## What remains unverified

- Real OAK-D operation and sequential DepthAI v2/v3 reopen on the Raspberry Pi.
- Dependency installation, native SDK/MediaPipe compatibility and real frame throughput.
- Accuracy of AprilTag pose, hand recognition, ground estimation, obstacle masks and path planning on real images.
- Actual vehicle stopping/holding, VESC controller-side timeout, steering calibration or duty-to-speed behavior.
- Arduino Mega board compilation/upload, electrical timing under interrupts, wiring and USB reset behavior.
- Servo range, real lift position, calibrated travel, limit protection, driver current and payload capacity.

The software therefore supports confidence in the tested coordination logic. It is not a guarantee that the physical robot will work without bench validation. Hardware mode intentionally requires supervised physical confirmations; it does not fabricate sensor feedback.

The thumbs-up classifier tests use synthetic landmarks for both mirrored hands and rejection of sideways/downward thumbs. They do not validate recognition accuracy on real hand images.

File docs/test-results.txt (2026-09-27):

test_drive_guard_expires_without_parent_updates (test_adapters.AdapterTests.test_drive_guard_expires_without_parent_updates) ... ok
test_drive_guard_reports_serial_failure (test_adapters.AdapterTests.test_drive_guard_reports_serial_failure) ... ok
test_legacy_firmware_rejected (test_adapters.AdapterTests.test_legacy_firmware_rejected) ... ok
test_real_subprocess_round_trip_and_exclusive_camera (test_adapters.AdapterTests.test_real_subprocess_round_trip_and_exclusive_camera) ... ok
test_same_resolved_ports_rejected (test_adapters.AdapterTests.test_same_resolved_ports_rejected) ... ok
test_serial_disconnect_is_not_swallowed (test_adapters.AdapterTests.test_serial_disconnect_is_not_swallowed) ... ok
test_serial_partial_lines_and_command_responses (test_adapters.AdapterTests.test_serial_partial_lines_and_command_responses) ... ok
test_unknown_port_rejected (test_adapters.AdapterTests.test_unknown_port_rejected) ... ok
test_empty_or_behind_path_stops (test_adapters.ControllerTests.test_empty_or_behind_path_stops) ... ok
test_near_endpoint_no_longer_stops_short (test_adapters.ControllerTests.test_near_endpoint_no_longer_stops_short) ... ok
test_near_obstacle_stops (test_adapters.ControllerTests.test_near_obstacle_stops) ... ok
test_all_compartment_commands_match_protocol (test_coordinator.CoordinatorTests.test_all_compartment_commands_match_protocol) ... ok
test_arduino_reset_invalidates_position (test_coordinator.CoordinatorTests.test_arduino_reset_invalidates_position) ... ok
test_both_release_and_exit_required (test_coordinator.CoordinatorTests.test_both_release_and_exit_required) ... ok
test_busy_lift_ignores_additional_selections (test_coordinator.CoordinatorTests.test_busy_lift_ignores_additional_selections) ... ok
test_complete_round_trip_and_fresh_target_required (test_coordinator.CoordinatorTests.test_complete_round_trip_and_fresh_target_required) ... ok
test_different_target_cannot_drive (test_coordinator.CoordinatorTests.test_different_target_cannot_drive) ... ok
test_duplicate_frames_neither_count_nor_extend_lease (test_coordinator.CoordinatorTests.test_duplicate_frames_neither_count_nor_extend_lease) ... ok
test_exit_before_release_order (test_coordinator.CoordinatorTests.test_exit_before_release_order) ... ok
test_held_selection_does_not_repeat (test_coordinator.CoordinatorTests.test_held_selection_does_not_repeat) ... ok
test_missing_done_faults_without_retry (test_coordinator.CoordinatorTests.test_missing_done_faults_without_retry) ... ok
test_near_tag_on_resume_remains_parked (test_coordinator.CoordinatorTests.test_near_tag_on_resume_remains_parked) ... ok
test_no_new_frames_expire_drive_and_fault (test_coordinator.CoordinatorTests.test_no_new_frames_expire_drive_and_fault) ... ok
test_nonfinite_command_faults (test_coordinator.CoordinatorTests.test_nonfinite_command_faults) ... ok
test_old_session_cannot_drive_in_gesture (test_coordinator.CoordinatorTests.test_old_session_cannot_drive_in_gesture) ... ok
test_release_timeout_does_not_start_second_camera (test_coordinator.CoordinatorTests.test_release_timeout_does_not_start_second_camera) ... ok
test_shutdown_cancels_pending_motion (test_coordinator.CoordinatorTests.test_shutdown_cancels_pending_motion) ... ok
test_stale_frame_faults (test_coordinator.CoordinatorTests.test_stale_frame_faults) ... ok
test_startup_timeout (test_coordinator.CoordinatorTests.test_startup_timeout) ... ok
test_stop_confirmation_required_and_arrival_latched (test_coordinator.CoordinatorTests.test_stop_confirmation_required_and_arrival_latched) ... ok
test_target_loss_and_obstacle_withdraw_drive (test_coordinator.CoordinatorTests.test_target_loss_and_obstacle_withdraw_drive) ... ok
test_worker_crash_faults (test_coordinator.CoordinatorTests.test_worker_crash_faults) ... ok
test_wrong_completion_id_faults (test_coordinator.CoordinatorTests.test_wrong_completion_id_faults) ... ok
test_different_gesture_and_neutral_rearm (test_coordinator.FilterTests.test_different_gesture_and_neutral_rearm) ... ok
test_no_hand_breaks_stability (test_coordinator.FilterTests.test_no_hand_breaks_stability) ... ok
test_actual_firmware_with_fake_arduino (test_firmware.FirmwareTests.test_actual_firmware_with_fake_arduino) ... ok
test_background_worker_stops_and_propagates_model_failure (test_perception_lifecycle.PerceptionLifecycleTests.test_background_worker_stops_and_propagates_model_failure) ... ok
test_bad_hold_settings_rejected (test_resume_gesture.HoldAndClassifierTests.test_bad_hold_settings_rejected) ... ok
test_existing_selection_gestures_remain_distinct (test_resume_gesture.HoldAndClassifierTests.test_existing_selection_gestures_remain_distinct) ... ok
test_hold_uses_elapsed_time_not_frame_count (test_resume_gesture.HoldAndClassifierTests.test_hold_uses_elapsed_time_not_frame_count) ... ok
test_sideways_down_and_fist_are_not_resume (test_resume_gesture.HoldAndClassifierTests.test_sideways_down_and_fist_are_not_resume) ... ok
test_vertical_thumb_up_on_either_hand (test_resume_gesture.HoldAndClassifierTests.test_vertical_thumb_up_on_either_hand) ... ok
test_busy_extended_and_unverified_retraction_reject_resume (test_resume_gesture.ResumeTests.test_busy_extended_and_unverified_retraction_reject_resume) ... ok
test_capture_gap_restarts_hold (test_resume_gesture.ResumeTests.test_capture_gap_restarts_hold) ... ok
test_drive_fault_prevents_resume (test_resume_gesture.ResumeTests.test_drive_fault_prevents_resume) ... ok
test_duplicate_frames_cannot_finish_hold (test_resume_gesture.ResumeTests.test_duplicate_frames_cannot_finish_hold) ... ok
test_no_hand_interrupts_hold (test_resume_gesture.ResumeTests.test_no_hand_interrupts_hold) ... ok
test_pre_confirmation_frames_cannot_start_hold (test_resume_gesture.ResumeTests.test_pre_confirmation_frames_cannot_start_hold) ... ok
test_short_hold_then_two_second_hold (test_resume_gesture.ResumeTests.test_short_hold_then_two_second_hold) ... ok
test_typed_resume_no_longer_bypasses_gesture (test_resume_gesture.ResumeTests.test_typed_resume_no_longer_bypasses_gesture) ... ok
test_close_releases_port_when_stop_fails (test_vesc_bridge.BridgeTests.test_close_releases_port_when_stop_fails) ... ok
test_connection_error_propagates (test_vesc_bridge.BridgeTests.test_connection_error_propagates) ... ok
test_first_zero_after_driving_is_zero (test_vesc_bridge.BridgeTests.test_first_zero_after_driving_is_zero) ... ok
test_missing_verified_device_does_not_fallback (test_vesc_bridge.BridgeTests.test_missing_verified_device_does_not_fallback) ... ok
test_negative_never_repeats_forward_command (test_vesc_bridge.BridgeTests.test_negative_never_repeats_forward_command) ... ok
test_nonfinite_command_requests_zero_and_raises (test_vesc_bridge.BridgeTests.test_nonfinite_command_requests_zero_and_raises) ... ok
test_numbered_or_unspecified_port_rejected (test_vesc_bridge.BridgeTests.test_numbered_or_unspecified_port_rejected) ... ok
test_serial_error_propagates_without_reconnection (test_vesc_bridge.BridgeTests.test_serial_error_propagates_without_reconnection) ... ok
test_short_write_is_error (test_vesc_bridge.BridgeTests.test_short_write_is_error) ... ok
test_gesture_processes_fresh_frames_without_browser_and_closes (test_vision_workers.VisionWorkerTests.test_gesture_processes_fresh_frames_without_browser_and_closes) ... ok
test_navigation_camera_error_closes_without_release_success (test_vision_workers.VisionWorkerTests.test_navigation_camera_error_closes_without_release_success) ... ok
test_navigation_worker_is_camera_only_and_emits_commands (test_vision_workers.VisionWorkerTests.test_navigation_worker_is_camera_only_and_emits_commands) ... ok

----------------------------------------------------------------------
Ran 62 tests in 5.460s

OK

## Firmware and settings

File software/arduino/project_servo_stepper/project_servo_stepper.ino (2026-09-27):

// RoboButler integration firmware, protocol ROBOBUTLER1.
// Existing pins, pulse limits, pulse count and speed retained; NOT calibrated.
// STOW is a physical operator confirmation, not a position sensor.
#include <Servo.h>
#include <stdlib.h>
#include <string.h>

const int SERVO_PIN = 5, DIR_PIN = 2, STEP_PIN = 3;
const int ENABLE_PIN = 8;
const bool USE_ENABLE_PIN = false;
const int SERVO_MIN_US = 500, SERVO_MAX_US = 2500, SERVO_MAX_DEG = 270;
const int STEPS_PER_TRAVEL = 300;  // Pulse count, NOT verified revolutions/travel.
const unsigned long STEP_HALF_US = 1000;
const unsigned long LINK_TIMEOUT_MS = 2000;

Servo myServo;
enum Position { UNKNOWN, STOWED, EXTENDED, RETRACTED_UNVERIFIED };
enum Motion { IDLE, SERVO_WAIT, STEPPING };
Position position = UNKNOWN;
Motion motion = IDLE;
unsigned long activeId = 0, lastId = 0, servoStart = 0, lastEdge = 0;
unsigned long lastHost = 0;
bool linked = false, extending = false, stepHigh = false;
int completedPulses = 0;
char lineBuffer[64];
unsigned int lineLength = 0;
bool droppingLine = false;

void response(const char* kind, unsigned long id) {
  Serial.print(kind); Serial.print(' '); Serial.println(id);
}
void complete(const char* state) {
  Serial.print("DONE "); Serial.print(activeId); Serial.print(' '); Serial.println(state);
}
void halt(const char* reason) {
  motion = IDLE;
  position = UNKNOWN;
  stepHigh = false;
  digitalWrite(STEP_PIN, LOW);
  // Do not drop holding torque or detach servo automatically under a load.
  Serial.print("FAULT "); Serial.println(reason);
}
void beginSteps(bool forward) {
  extending = forward;
  digitalWrite(DIR_PIN, forward ? HIGH : LOW);
  digitalWrite(STEP_PIN, LOW);
  completedPulses = 0;
  stepHigh = false;
  lastEdge = micros();  // Full low interval also satisfies direction setup delay.
  motion = STEPPING;
}
void processLine(char* text) {
  if (!strcmp(text, "STOP")) { halt("STOPPED"); return; }
  if (!strcmp(text, "HELLO")) {
    linked = true; lastHost = millis();
    Serial.println("READY ROBOBUTLER1"); return;
  }
  if (!strcmp(text, "PING")) {
    if (linked) { lastHost = millis(); Serial.println("PONG"); }
    return;
  }
  if (!linked) { halt("NOT_LINKED"); return; }
  if (text[0] < '1' || text[0] > '9') { halt("BAD_ID"); return; }
  char* end;
  unsigned long id = strtoul(text, &end, 10);
  if (end == text || *end != ' ' || id == 0 || id <= lastId) {
    halt("BAD_ID"); return;
  }
  const char* command = end + 1;
  if (motion != IDLE) { halt("BUSY"); return; }
  bool selection = !strcmp(command, "Command_1") || !strcmp(command, "Command_2") ||
                   !strcmp(command, "Command_3") || !strcmp(command, "Command_4");
  if (!strcmp(command, "STOW")) {
    if (position == EXTENDED) { halt("NOT_RETRACTED"); return; }
    lastId = activeId = id;
    position = STOWED;
    response("ACK", id); complete("STOWED");
  } else if (selection && position == STOWED) {
    lastId = activeId = id;
    response("ACK", id);
    int degrees = (command[8] - '1') * 90;
    if (!myServo.attached()) myServo.attach(SERVO_PIN, SERVO_MIN_US, SERVO_MAX_US);
    myServo.writeMicroseconds(map(degrees, 0, SERVO_MAX_DEG, SERVO_MIN_US, SERVO_MAX_US));
    position = UNKNOWN;
    servoStart = millis();
    motion = SERVO_WAIT;
  } else if (!strcmp(command, "RETURN") && position == EXTENDED) {
    lastId = activeId = id;
    response("ACK", id);
    position = UNKNOWN;
    beginSteps(false);
  } else {
    halt("INVALID_STATE_OR_COMMAND");
  }
}
void setup() {
  Serial.begin(9600);
  pinMode(DIR_PIN, OUTPUT); pinMode(STEP_PIN, OUTPUT);
  digitalWrite(STEP_PIN, LOW);
  if (USE_ENABLE_PIN) { pinMode(ENABLE_PIN, OUTPUT); digitalWrite(ENABLE_PIN, LOW); }
  // No servo movement and no assumed lift home position at startup.
  Serial.println("BOOT ROBOBUTLER1");
}
void loop() {
  // Bounded serial work so motor timing is not starved by excessive input.
  for (int n = 0; n < 32 && Serial.available(); ++n) {
    char c = (char)Serial.read();
    if (c == '\r') continue;
    if (c == '\n') {
      if (!droppingLine) { lineBuffer[lineLength] = '\0'; processLine(lineBuffer); }
      lineLength = 0; droppingLine = false;
    } else if (!droppingLine) {
      if (lineLength < sizeof(lineBuffer) - 1) lineBuffer[lineLength++] = c;
      else { droppingLine = true; halt("LINE_TOO_LONG"); }
    }
  }
  if (linked && (unsigned long)(millis() - lastHost) > LINK_TIMEOUT_MS) {
    linked = false; halt("LINK_TIMEOUT");
  }
  if (motion == SERVO_WAIT && (unsigned long)(millis() - servoStart) >= 800) {
    beginSteps(true);
  }
  if (motion == STEPPING && (unsigned long)(micros() - lastEdge) >= STEP_HALF_US) {
    lastEdge = micros();
    stepHigh = !stepHigh;
    digitalWrite(STEP_PIN, stepHigh ? HIGH : LOW);
    if (!stepHigh && ++completedPulses >= STEPS_PER_TRAVEL) {
      motion = IDLE;
      position = extending ? EXTENDED : RETRACTED_UNVERIFIED;
      complete(extending ? "EXTENDED" : "RETRACTED_UNVERIFIED");
    }
  }
}

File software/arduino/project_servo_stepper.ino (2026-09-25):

#include <Servo.h>

// -------------------- Pin Definitions --------------------
const int SERVO_PIN = 5;

const int DIR_PIN = 2;
const int STEP_PIN = 3;

// Optional enable pin
const int ENABLE_PIN = 8;
const bool USE_ENABLE_PIN = false;

// -------------------- Servo --------------------
Servo myServo;

// For 270-degree servo
const int SERVO_MIN_US = 500;
const int SERVO_MAX_US = 2500;
const int SERVO_MAX_DEG = 270;

// -------------------- Stepper Settings --------------------
int stepDelayMicros = 1000;

// Change this until one full stepper rotation is correct
const int STEPS_PER_ROTATION = 300;

bool liftExtended = false;

void setup() {
  Serial.begin(9600);

  pinMode(DIR_PIN, OUTPUT);
  pinMode(STEP_PIN, OUTPUT);

  if (USE_ENABLE_PIN) {
    pinMode(ENABLE_PIN, OUTPUT);
    digitalWrite(ENABLE_PIN, LOW);
  }

  myServo.attach(SERVO_PIN);
  moveServoDegrees(0);

  Serial.println("Arduino ready.");
  Serial.println("Commands:");
  Serial.println("Command_1");
  Serial.println("Command_2");
  Serial.println("Command_3");
  Serial.println("Command_4");
  Serial.println("RETURN");
  Serial.println("TEST");

  delay(1000);
}

void loop() {
  if (Serial.available() > 0) {
    String command = Serial.readStringUntil('\n');
    command.trim();

    Serial.print("Received: ");
    Serial.println(command);

    if (command == "Command_1" && liftExtended == false) {
      moveServoDegrees(0);
      delay(800);
      moveStepper(true, STEPS_PER_ROTATION);
      liftExtended = true;
      Serial.println("Command_1 complete: servo 0, stepper extended");
    }

    else if (command == "Command_2" && liftExtended == false) {
      moveServoDegrees(90);
      delay(800);
      moveStepper(true, STEPS_PER_ROTATION);
      liftExtended = true;
      Serial.println("Command_2 complete: servo 90, stepper extended");
    }

    else if (command == "Command_3" && liftExtended == false) {
      moveServoDegrees(180);
      delay(800);
      moveStepper(true, STEPS_PER_ROTATION);
      liftExtended = true;
      Serial.println("Command_3 complete: servo 180, stepper extended");
    }

    else if (command == "Command_4" && liftExtended == false) {
      moveServoDegrees(270);
      delay(800);
      moveStepper(true, STEPS_PER_ROTATION);
      liftExtended = true;
      Serial.println("Command_4 complete: servo 270, stepper extended");
    }

    else if (command == "RETURN" && liftExtended == true) {
      moveStepper(false, STEPS_PER_ROTATION);
      liftExtended = false;
      Serial.println("Returned to rest");
    }

    else if (command == "TEST") {
      runMotorTest();
    }

    else {
      Serial.print("Ignored or unknown command: ");
      Serial.println(command);
    }
  }
}

void moveServoDegrees(int degrees) {
  degrees = constrain(degrees, 0, SERVO_MAX_DEG);

  int pulseWidth = map(degrees, 0, SERVO_MAX_DEG, SERVO_MIN_US, SERVO_MAX_US);

  myServo.writeMicroseconds(pulseWidth);
}

void moveStepper(bool clockwise, int steps) {
  digitalWrite(DIR_PIN, clockwise ? HIGH : LOW);
  delayMicroseconds(50);

  for (int i = 0; i < steps; i++) {
    digitalWrite(STEP_PIN, HIGH);
    delayMicroseconds(stepDelayMicros);

    digitalWrite(STEP_PIN, LOW);
    delayMicroseconds(stepDelayMicros);
  }
}

void runMotorTest() {
  Serial.println("Running motor test...");

  moveServoDegrees(0);
  delay(1000);

  moveServoDegrees(90);
  delay(1000);

  moveServoDegrees(180);
  delay(1000);

  moveServoDegrees(270);
  delay(1000);

  moveServoDegrees(0);
  delay(1000);

  moveStepper(true, STEPS_PER_ROTATION);
  delay(1000);

  moveStepper(false, STEPS_PER_ROTATION);
  delay(1000);

  Serial.println("Motor test complete.");
}
